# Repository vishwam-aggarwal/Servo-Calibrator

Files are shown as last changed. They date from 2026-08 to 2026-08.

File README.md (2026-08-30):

# Servo Calibrator

A browser-based tool that characterizes a hobby RC servo — finds its real
pulse range and builds a 20-point calibration lookup table, fully
automated, one button — then lets you drive and visualize trajectories
against that calibration live, using an AS5600 magnetic encoder as
ground truth instead of a protractor and guesswork.

**Purely for characterization.** This tool doesn't generate a driver
constructor, doesn't ask about horn installation, direction, or a
logical zero point — it always works in the servo's own physical frame,
`[0, maxAngle]`. Turning a measured range/table into an actual
`RCServoMotorDriver`/`PCA9685MotorDriver` constructor (direction, mounting
offset, logical framing) is an application concern, left to your own
[Universal-Motor-Interface](#the-calibration-table--universal-motor-interface)
code.

No install, no build step. It's one HTML file that talks to an Arduino
over [Web Serial](https://developer.mozilla.org/en-US/docs/Web/API/Web_Serial_API).

> **Status:** the firmware is a self-contained FSM (`ServoCalibrator_Companion.ino`)
> verified against real hardware — most recently a full
> `CAL` → `GETTABLE` → `GO` round trip on an Arduino Nano R4, where a
> 20-point table cut mean positioning error from 3.13° (naive linear) to
> **0.19°** across five targets. The app (`website/app.html`) was
> rewritten against that firmware and verified against the real page
> code — real captured hardware wire data fed straight into `SerialLink`,
> calibration parsing, and the charts — but **not yet exercised through
> an actual live `navigator.serial` session** (the browser's native port
> picker needs a human at the keyboard; that pass is still open). See
> [Known limitations](#known-limitations) for what's still rough. **The
> firmware depends on three sibling libraries — Universal-Encoder-Interface,
> Universal-Trajectory-Interface, and the Universal-Device-Interface base
> they both build on — plus RobTillaart's `AS5600`. All public, no private
> access needed** — see
> [Dependencies](#requirements--dependencies) before you try to build it.

## Contents

- [Why this exists](#why-this-exists)
- [Quick start](#quick-start)
- [What it looks like in use](#what-it-looks-like-in-use)
- [How it works](#how-it-works)
- [The calibration table & Universal-Motor-Interface](#the-calibration-table--universal-motor-interface)
- [Export](#export)
- [Wiring](#wiring)
- [Requirements & dependencies](#requirements--dependencies)
- [Safety notes](#safety-notes)
- [Serial protocol reference](#serial-protocol-reference)
- [Known limitations](#known-limitations)
- [License](#license)

## Why this exists

Hobby servos have a real, measurable non-linear bow in their pulse↔angle
response — a plain 2-point linear formula (the usual assumption) leaves
several degrees of avoidable error on the table. Characterizing that
curve by hand (jogging pulses, reading a protractor, building a table
yourself) is slow and imprecise. This tool automates the whole thing: an
AS5600 magnetic encoder on the servo's output shaft gives ground-truth
angle feedback, and the firmware itself stall-scans the servo's real
mechanical limits and sweeps the full range to build a direction-averaged
lookup table — no hand-measurement, no guessing. Then, because the same
rig is already wired up, it doubles as a small live trajectory
visualizer — closer to a mini ODrive GUI than a calibration wizard — so
you can actually *see* what that calibration buys you before writing any
application code.

## Quick start

1. **Install the four libraries this firmware needs** — all free,
   no private access required (see
   [Requirements & dependencies](#requirements--dependencies)):
   - **`AS5600`** (RobTillaart's), via the Arduino IDE's own Library
     Manager: `Sketch → Include Library → Manage Libraries…`, search
     `AS5600`, install the one by RobTillaart. Or from the command line:
     `arduino-cli lib install "AS5600"`. Still needed — the firmware
     reaches it through Universal-Encoder-Interface rather than directly,
     but that's a wrapper, not a replacement.
   - **[Universal-Encoder-Interface](https://github.com/vishwam-aggarwal/Universal-Encoder-Interface)**
     — install manually, same as the two below. Provides
     `AS5600EncoderDriver`, which owns the multi-turn (across-revolution)
     position tracking this firmware depends on.
   - **[Universal-Trajectory-Interface](https://github.com/vishwam-aggarwal/Universal-Trajectory-Interface)**
     — not in Library Manager's index (it's not a published Arduino
     library, just a public GitHub repo), so install it manually:
     download the repo as a ZIP from GitHub (`Code → Download ZIP`) and
     use `Sketch → Include Library → Add .ZIP Library…`, pointing at
     that ZIP — the IDE unpacks it into your sketchbook's `libraries/`
     folder itself. (Equivalently: `git clone` it directly into your
     Arduino `libraries/` folder, e.g.
     `~/Documents/Arduino/libraries/Universal-Trajectory-Interface` — same
     result, no rename needed since the repo already has a proper
     `library.properties`.) Restart the IDE afterward if it was already
     open, so it picks up the new library.
   - **[Universal-Device-Interface](https://github.com/vishwam-aggarwal/Universal-Device-Interface)**
     — the foundation layer both of the above declare, so it's needed even
     though this firmware never includes anything from it directly.
     Universal-Encoder-Interface's `IEncoder` derives from its `IDevice`;
     separately, the Arduino IDE compiles every `.cpp` in a library's
     `src/`, so Universal-Trajectory-Interface's `TrajectoryGroup.cpp` /
     `CartesianMove.cpp` (neither of which this sketch uses) pull in
     `<IDevice.h>` regardless. Without it the build stops at
     `fatal error: IDevice.h: No such file or directory`. Install it
     exactly the same way as above (ZIP or `git clone` into
     `libraries/`), also public.
2. **Flash the firmware.** Open `ServoCalibrator_Companion/ServoCalibrator_Companion.ino`
   in the Arduino IDE (or `arduino-cli`) and upload it to your board.
   Servo signal is fixed at pin `A3` (change `SERVO_PIN` in the sketch if
   you need a different pin — unlike the firmware's predecessor, this
   isn't runtime-configurable, since there's no wizard step left to ask).
3. **Wire it up**: servo signal to `A3`, AS5600 on the board's I²C bus
   (`SDA`/`SCL`), servo power from an external supply sized for your
   servo (not the Arduino's own 5V pin on most boards — see
   [Wiring](#wiring)).
4. **Open the app.** `website/app.html` needs to be served over
   `http://` — Web Serial does not reliably work when a page is opened
   directly as a `file://` URL. (A hosted copy is also planned at
   [vishwamaggarwal.com/tools/servo-calibrator/](https://vishwamaggarwal.com/tools/servo-calibrator/),
   once that page is out of draft — no local setup needed there.) The
   easiest way to run it from this repo in the meantime:
   ```bash
   # from website/
   python -m http.server 8000
   # or: npx serve
   ```
   then open `http://localhost:8000/app.html` in **Chrome or
   Edge** (Web Serial isn't implemented in Firefox or Safari).
5. **Connect, then Calibrate.** Click *Connect…*, pick your serial port
   in the browser's device picker, then click **Calibrate** — one
   button, fully automated, usually done in under a minute. The command
   acknowledges immediately and the run streams progress asynchronously;
   the command/chart interface below unlocks once the app sees the
   table finish (there's no separate "done" reply — see
   [Serial protocol reference](#serial-protocol-reference)). Every large
   move the firmware makes during calibration is deliberately slow and
   incremental (small steps, a short pause between each) rather than one
   instant jump — found to be necessary against at least one real servo
   that behaved oddly when commanded a big pulse change in one shot (see
   `CLAUDE.md` for the story); it's expected, not a stall. This firmware
   doesn't remember a calibration across a reconnect — recalibrate fresh
   every session.

## What it looks like in use

- **Calibration**: click Calibrate. The firmware coarse-then-fine scans
  outward from center in both directions — each scan self-calibrates its
  own baseline step rate from its first few real steps, then watches
  every step after that for a weak, reversed, or oversized-jump response
  *relative to that rate* (no fixed threshold) — to find the real safe
  pulse range, then sweeps it twice (once each direction) to build a
  20-point direction-averaged table. Progress streams into the log live.
  Result: a summary (`350–2630µs · 214.01° stroke · 20-point table`) and
  an **Export table…** button.
- **Live trace**: command a single point-to-point move (a real,
  v<sub>max</sub>/a<sub>max</sub>-limited trapezoidal move to a target
  angle — no continuous square-wave/sine-wave generator; this firmware
  deliberately only ever streams one planned move at a time). Three
  auto-scaled rolling charts (position, velocity, error) show setpoint
  vs. AS5600-measured actual, live — velocity's "actual" trace comes
  straight from the firmware's own encoder-derivative measurement, not a
  client-side numeric differentiation.
- **See the table's improvement, interactively**: a toggle switches
  between the plain 2-point linear formula and the just-calibrated
  20-point table (at rest only — like every other command, `MODEL` is
  rejected while a move is actively running) — and the error chart's
  line is colored by which model was active, next to a running
  mean-error-per-model comparison, so the improvement is something you
  watch happen, not a number you take on faith.

## How it works

Two pieces:

- **`ServoCalibrator_Companion.ino`** — a self-contained finite state
  machine, one `switch`/`case` in `loop()`, fixed 50Hz tick, running
  both the calibration routine and trajectory execution itself,
  on-device. Unlike a blocking one-shot design, `CAL` acknowledges
  immediately and the calibration routine runs as part of the normal
  tick loop — the board never stops responding to serial while it runs
  (`PING`/`ABORT` both still work mid-calibration). Once calibrated,
  [`TrapezoidalProfile`](https://github.com/vishwam-aggarwal/Universal-Trajectory-Interface)
  is planned/evaluated on-device at that same fixed ~50Hz, alongside
  telemetry that streams unconditionally every tick regardless of
  state — the app never paces the motion, it only sends target/limit
  commands and plots what comes back. Every encoder read goes through
  [`AS5600EncoderDriver`](https://github.com/vishwam-aggarwal/Universal-Encoder-Interface)
  in continuous mode, which is what keeps the angle accumulating across
  full revolutions instead of snapping back at each wrap — the firmware
  used to do that unwrapping itself and no longer does.
- **`website/app.html`** — the app. Connection, calibration
  triggering/export, and the three live charts all live here; the
  firmware doesn't know anything about SVG or the exported `.h` file's
  format. The firmware's own calibration table is re-anchored to a 0°
  low endpoint on-device (see
  [Serial protocol reference](#serial-protocol-reference)), so the app
  no longer does any of that framing itself — it just plots/sends what
  the firmware already reports in the established physical
  `[0, maxAngleDeg]` convention.

## The calibration table & Universal-Motor-Interface

The table this tool builds is a plain array of `{pulseUs, angleCentideg}`
pairs (`CalPoint`) — the firmware's own self-contained type, **not**
an include of [Universal-Motor-Interface](https://github.com/vishwam-aggarwal/Universal-Motor-Interface)'s
`ServoCalibrationTable.h` (building/uploading this sketch needs no UMI
access at all — see [Requirements & dependencies](#requirements--dependencies)).
It's deliberately shaped like UMI's own `CalPoint` — same fields, same
angle↔pulse interpolation algorithm — but not identical (`int32_t`
angles here vs. UMI's `int16_t`, to handle this firmware's unbounded
multi-turn position tracking) and lives entirely in `ServoCalibrator_Companion.ino`
itself. The table is also normalized to the same `[0, maxAngleDeg]`
frame UMI's `validateCalTable()` expects (index 0 at exactly 0°,
strictly ascending) — done on-device, once, right when a calibration
finishes, so `GETTABLE`'s own wire output already satisfies it with no
client-side transform needed. Export (see [below](#export)) generates a
standalone `.h` file with a plain `CalPoint` struct and populated array
in that exact shape, to hand to `RCServoMotorDriver`'s/`PCA9685MotorDriver`'s
table-accepting constructor overload by whatever *consuming* application
installs this servo (one edit needed first — those drivers require a
`PROGMEM` table; see [Export](#export)) — that's where UMI actually comes in, downstream,
not in building this tool. Physical testing
across two servos (140 to 22,000+ samples, in the investigation that
motivated this whole tool) found a 20-point table cuts mean positioning
error 2–6× vs. the linear formula, for ~80 bytes of `PROGMEM`.

**This tool deliberately doesn't generate the constructor call itself.**
The old wizard-based version of this repo did (see git history) — this
version doesn't, because direction, logical zero, and mounting offset are
all *installation*-specific decisions this characterization-only tool has
no way to know. Export the table (see [below](#export)) — it's already a
`CalPoint` array in the right shape and framing, no manual transcription
needed — add `PROGMEM` to its declaration (see [Export](#export) for why
that one edit isn't optional), and pass it to
`RCServoMotorDriver`'s/`PCA9685MotorDriver`'s table-accepting
constructor overload alongside whatever direction/offset your actual
installation needs.

## Export

**Export** queries the firmware for its current table (`GETTABLE`, a
genuine on-demand round trip, not a reuse of whatever the app happened to
capture live off the original `CAL` run's own `TABLE` stream) and
downloads it as a standalone `.h` file: a plain
`struct CalPoint { uint16_t pulseUs; int16_t angleCentideg; }` — matching
UMI's own `ServoCalibrationTable.h` field-for-field, though the file
itself never mentions UMI — plus a populated
`static const CalPoint SERVO_CAL_TABLE[]` array, already in the firmware's
own `[0, maxAngleDeg]` framing (see
[How it works](#how-it-works)). It's a plain RAM array, not `PROGMEM` —
directly readable with no special macro whether or not the consuming
code ever touches UMI.

> **Add `PROGMEM` before handing it to a UMI driver.** This is not the
> optional flash-vs-RAM tradeoff it reads like. UMI's
> `ServoCalibrationTable.h` reads every entry through `readCalPoint()`,
> which calls `pgm_read_word()` unconditionally — so on AVR, where flash
> and RAM are separate address spaces, passing a plain RAM array to
> `RCServoMotorDriver`/`PCA9685MotorDriver` reads flash at the same
> numeric address and gets garbage. In practice `validateCalTable()` then
> rejects the nonsense (the driver falls back to the linear formula and
> reports `ERR_INVALID_CAL_TABLE` once), so it isn't silent — but it also
> isn't the table you measured. Add `PROGMEM` to the array declaration
> and it works as intended. The exported file says the same thing in its
> own header comment, phrased generically, since it's deliberately
> written to be usable outside UMI too.

Note also that the emitted `angleCentideg` field is `int16_t`, matching
UMI's `CalPoint` — so it tops out at 327.67°. The firmware's own table is
`int32_t` and has no such limit, so Export refuses outright (rather than
writing a table that would silently wrap once compiled) if a servo ever
measures a stroke past that. There's no matching **Import** — this
firmware has no command that accepts a pushed-in table, unlike its
predecessor. `GETTABLE` only ever answers for the *current* session,
too: opening the port always reboots the board, wiping its table, so
every reconnect still needs a fresh Calibrate before Export works again.
Export exists purely for keeping a record of what a servo measured at,
not for skipping a future physical recalibration of that same servo.

## Wiring

- **Servo signal** → `A3` (fixed in firmware — see [Quick start](#quick-start)
  if you need a different pin).
- **AS5600** → the board's I²C bus (`SDA`/`SCL` — `A4`/`A5` on an
  Uno/Nano), with the magnet mounted on the servo's output shaft, centered
  over the chip.
- **Servo power** → an external supply sized for your servo's stall
  current, **not** the Arduino's own 5V/Vin pin on most small boards —
  clone/small-board regulators usually can't source enough current, and
  Vin specifically needs headroom above 5V to regulate down cleanly (it
  is not a direct 5V input). Common ground between the supply, the servo,
  and the Arduino either way.

## Requirements & dependencies

**Hardware:**

- An Arduino-compatible board with I²C and a free PWM-capable digital
  pin (`A3` by default).
- An AS5600 breakout, magnet mounted on the servo's output shaft.

**Software, to build the firmware:**

| Library | Used for | Status |
|---|---|---|
| [RobTillaart's `AS5600`](https://github.com/RobTillaart/AS5600) | Low-level AS5600 I²C register access | Public — `arduino-cli lib install "AS5600"` or via Library Manager |
| [**Universal-Trajectory-Interface**](https://github.com/vishwam-aggarwal/Universal-Trajectory-Interface) (mine) | `TrapezoidalProfile` — used **unconditionally** | **Public** |
| [**Universal-Encoder-Interface**](https://github.com/vishwam-aggarwal/Universal-Encoder-Interface) (mine) | `AS5600EncoderDriver` — the AS5600 read path and its multi-turn unwrap | **Public** |
| [**Universal-Device-Interface**](https://github.com/vishwam-aggarwal/Universal-Device-Interface) (mine) | Nothing, directly — it's the base both siblings above declare (`depends=Universal Device Interface`), and the Arduino IDE compiles a library's whole `src/` regardless of what the sketch includes | **Public** |

In short: anyone with these four libraries installed (see
[Quick start](#quick-start)) can build and upload this firmware —
**no private dependency remains**. Universal-Device-Interface joined the
list on 2026-08-29, when Universal-Trajectory-Interface's `TrajectoryGroup`
and `CartesianMove` were retrofitted onto its shared `IDevice` base; the
per-axis profile math this firmware actually uses (`TrapezoidalProfile`)
was deliberately left off that base and is unchanged, so that library is
purely an install-time requirement here, not an API change.
Universal-Encoder-Interface joined at the same time, when this firmware's
hand-rolled AS5600 multi-turn tracking was replaced by its
`AS5600EncoderDriver`.

> **On an ATmega328P specifically** (the classic Nano this project was
> developed on), the firmware now uses 78% of SRAM and `arduino-cli`
> prints `Low memory available, stability problems may occur`. About 230
> bytes of that is structural rather than avoidable: on AVR a class's
> diagnostic strings live in RAM, and Universal-Encoder-Interface's
> `IDevice` vtable keeps every one of `AS5600EncoderDriver`'s reachable
> whether this sketch calls them or not. It builds and links cleanly, and
> there is no such pressure on a 32-bit board (an Arduino Nano R4 comes in
> at 22% of its SRAM) — but on a 328P, that's the first thing to suspect
> if you hit instability.

`ServoCalibrator_Companion` does
**not** depend on Universal-Motor-Interface, despite an earlier version
of this doc claiming otherwise — its calibration-table code (`CalPoint`,
angle↔pulse interpolation) is a self-contained reimplementation in the
`.ino` itself, not an actual include of UMI's `ServoCalibrationTable.h`.
See [The calibration table](#the-calibration-table--universal-motor-interface)
below for where UMI *is* still relevant (downstream, for a consuming
application), just not for building this sketch.

**Browser:** Chrome or Edge (desktop) — Web Serial isn't available in
Firefox or Safari.

## Safety notes

- **Calibrate with a bare horn.** No linkage, mechanism, gearbox, or load
  attached — a loaded mechanism can make a stall look like normal
  resistance and vice versa. Recalibrate (re-run `CAL`) if you change the
  mechanical load after the fact.
- `CAL` deliberately drives the servo into its mechanical end stops to
  find them (with active recovery if the servo spins past a limit
  instead of stalling, rather than just timing out — see `CLAUDE.md`).
  It stops advancing within a small margin of first detecting no motion,
  so it only grinds against a stop briefly — but it is intentionally
  doing that, twice (once per direction), by design.
- A hard pulse-width safety ceiling (80–2912µs, fixed in firmware) exists
  as a fail-safe in case stall detection doesn't trigger for some reason
  (e.g. an encoder fault) — a scan hitting it ends the run without a
  usable table, rather than silently accepting a bad range. If that
  happens to you, it likely means your servo's real range is wider than
  this default too — widen `ABS_FLOOR_US`/`ABS_CEIL_US` in the firmware
  and reflash. **Don't raise `ABS_CEIL_US` past 2912µs**: the AVR `Servo`
  library encodes `attach()`'s bounds in a signed `int8_t`, and anything
  higher silently overflows and wraps to a *lower* effective ceiling than
  before (2912 is the real representable max — see `CLAUDE.md`'s
  2026-08-25 entry for how this was found and what it cost).

## Serial protocol reference

115200 baud, one command per line, newline-terminated ASCII. Genuinely
different in shape from the predecessor firmware this repo used to have
at this path — see `CLAUDE.md`'s 2026-08-21 entry for the full design
story if you're diffing against an older version of this doc.

| Command | Response |
|---|---|
| `PING` | `OK PING` |
| `CAL` | `OK CAL` — acknowledges immediately; the run itself streams asynchronously (see below), no final reply |
| `ABORT` | `OK ABORT` \| `ERR ALREADY_IDLE` — cancels a calibration *or* a move; exempt from the busy-gate below |
| `ACCEL <aMaxDegS2>` | `OK ACCEL` |
| `VEL <vMaxDegS>` | `OK VEL` |
| `POS <targetDeg>` | `OK POS` \| `ERR NOT_CALIBRATED` \| `ERR POS_RANGE` — range-checked server-side against `[0, maxAngleDeg]` (the app also checks client-side first, to fail fast without a round trip) |
| `GO` | `OK GO` \| `ERR NOT_CALIBRATED` — starts a move to the most recently set `POS`, at the most recent `ACCEL`/`VEL` |
| `MODEL LINEAR\|TABLE` | `OK MODEL` \| `ERR NOT_CALIBRATED` |
| `GETTABLE` | `OK GETTABLE` \| `ERR NOT_CALIBRATED` — streams all 20 `TABLE` lines first (see below), *then* replies; no immediate ack the way `CAL`/`GO` get one |

While a calibration or move is running, every command except `ABORT` and
`PING` is rejected with `ERR BUSY`.

**Calibration streams three line shapes while it runs**, none of them a
reply to any pending command:

```
<elapsedMs> PROGRESS <stateName> <tick> <lastSentUs> <posCentideg>
<elapsedMs> TABLE <index> <pulseUs> <angleCentideg> <posCentideg>
<elapsedMs> ERR <code> <posCentideg>
```

That trailing `<posCentideg>` is a diagnostic field every one of these
lines carries: the current *filtered* shaft position, in raw-frame
centidegrees (relative to wherever the board booted, **not** normalized
to `[0, maxAngleDeg]`). It used to be raw AS5600 counts; it became
centidegrees when the encoder path moved to Universal-Encoder-Interface
and the internal position stopped being counts at all. Nothing parses
it — the app reads the fields ahead of it and ignores this one — so
treat it as a log aid, not protocol.

`TABLE` fires twice per index (20 points, down-pass then up-pass —
the up-pass value is the final, direction-averaged one); the app detects
completion by recognizing index 19 arriving *ascending* (immediately
after index 18), since there's no dedicated "done" message. `angleCentideg`
in this **live, mid-calibration** stream is still a **raw** encoder
reading relative to wherever the board happened to boot — normalization
only happens once, in memory, right after both passes finish (see
[How it works](#how-it-works)), so these in-flight lines are
progress-only; the app doesn't build the final calibration from them
any more, it just watches the index sequence for completion. `ERR` here
is an asynchronous internal failure (e.g. a settle timing out), not a
synchronous command rejection.

`GETTABLE` streams the identical `TABLE` line shape, once per index,
ascending — one entry per tick, oldest first, no down/up-pass repeat
this time (it's just replaying the already-built table, not measuring a
fresh one). Unlike the live stream above, `GETTABLE` always reflects the
table *after* normalization — index 0 at exactly 0°, strictly ascending
— since it's reading `calTable` at rest, not mid-scan. The app tells a
live-CAL `TABLE` line apart from a `GETTABLE` one by whether a
calibration is actually running, not by the line shape itself (same
shape either way), and always calls `GETTABLE` once calibration
completes to get the authoritative normalized table rather than trusting
what it watched go by live.

Telemetry streams every tick (~50Hz) from boot onward, unconditionally
— not only once calibrated, and regardless of state (idle,
mid-calibration, or mid-move):

```
TELEM <ms> <targetCentideg> <targetVelCentidegPerSec> <actualCentideg> <actualVelCentidegPerSec>
```

No mode/model field (unlike the old `T,...` line) — the app tracks which
model is live itself, since only it ever changes `MODEL`. A completed
move is signaled by exactly one `PROGRESS TRAJ_WAIT ...` line, printed
the instant the shaft settles. Lines starting with `#` are informational
(boot banner) — not part of the command/response or telemetry protocol.

## Known limitations

- **The browser app hasn't been exercised against a real live serial
  connection yet** — verified by feeding real captured hardware wire
  data directly into the actual page code (`claude-in-chrome`, not a
  reimplementation), but the `navigator.serial` port-picker itself needs
  a human at the keyboard to click through, and that pass hasn't
  happened yet.
- **No calibration persists across a reconnect.** `GETTABLE` can
  re-query the current session's table (used by Export), but opening the
  port always reboots the board — recalibrate every session regardless.
- **No table import**, only export — there's no command this firmware
  accepts a pushed-in table through. Export is for record-keeping, not
  for skipping a future recalibration.
- Tested on Chrome/Edge over `http://localhost`; opening the app
  directly via `file://` has not been confirmed to work reliably with
  Web Serial.
- No PCA9685 support in this firmware (the old wizard-era version had
  it; this characterization-only rewrite doesn't yet — `ServoCalibrationTable.h`'s
  math is transport-agnostic, so adding it back is mostly a matter of
  swapping the raw `Servo` calls for `PCA9685Backend` ones).
- Servo pin is fixed at compile time (`A3`) — no runtime pin
  configuration, unlike the old wizard-era firmware.
- No installer/packaged build — meant to stay a single portable HTML
  file, served locally.

Issues and pull requests welcome.

## License

MIT — see [`LICENSE`](LICENSE).

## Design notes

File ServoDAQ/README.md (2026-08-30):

# ServoDAQ

A second, unrelated tool in this repo — a companion firmware
(`ServoDAQ_Companion/ServoDAQ_Companion.ino`) plus a Python host driver
(`ServoDAQ_Host/`), not the Web-Serial browser app documented in the
[main README](../README.md). It exists for one-off bench
characterization/article-testing work — comparing a naive single-step
stall-detection sweep against a smarter coarse+fine, rate-based
`find_range()` on real hardware — and is deliberately kept separate from
`website/app.html`/`ServoCalibrator_Companion`: that tool stays
untouched, this kind of exploratory work goes in its own files instead.

No zero reference, no model, no calibration table — that's the host's
job. The firmware's only responsibilities are talking to the servo,
reading the AS5600, and turning that into a signed, monotonic,
multi-turn-unwrapped centidegree position (see the `.ino`'s own
file-level comment for how). Everything else — range-finding, deciding
what "the edge" means, plotting — lives in `ServoDAQ_Host/`.

**Libraries needed to build the firmware** (all public): RobTillaart's
`AS5600`, plus Universal-Encoder-Interface and its own base
Universal-Device-Interface. As of 2026-08-29 the multi-turn unwrap is
Universal-Encoder-Interface's `AS5600EncoderDriver` (continuous mode)
rather than a copy maintained here; the wire protocol is unchanged.

## Protocol

115200 baud, one command per line, `\n`-terminated ASCII.

- `PING` → `OK PONG`
- `US <pulseUs>` → `OK <pulseUs> <centideg>` (blocks until settled) |
  `ERR NOT_SETTLED <pulseUs> <centideg>` (the settle timeout elapsed
  without ever meeting the criterion — `centideg` here is just the last
  raw reading, not a trustworthy position; see "A servo that spins a
  full turn instead of stalling" below for why this reply exists)
- `CAP <pulseUs> <delayMs>` → streamed `CP <tMs> <centideg>` samples,
  `CAPEND <count>` — diagnostic raw step-response capture, for seeing
  motion the settle detector smooths over.

## Host scripts

- `servo_daq.py` — the library: `ServoDAQLink`, `sweep()`,
  `naive_stall_sweep()` (the dumb baseline), `find_range()`/`find_edge()`/
  `scan_until_weak()` (the coarse+fine rate-based algorithm).
- `study_range.py` — the full per-servo characterization pipeline, one
  connection/session: naive sweep → smart `find_range()` → fine (5µs,
  both directions) calibration sweep → N-point lookup-table accuracy
  test (see below). Written to run identically across different servos
  (same code path/phases/thresholds every time) — only the port and the
  accuracy-test duration are meant to vary between invocations.
- `plot_naive_vs_smart.py` — same comparison, but plots naive/coarse/fine
  as three separately colored traces (one connection/session, so the
  centideg reference is consistent across all of it).
- `plot_full_range.py` — reads a saved run's CSVs (no hardware access)
  and draws one combined-axis chart spanning the whole tested range, with
  markers at `find_range()`'s reported min/max.
- `probe_low_jump.py`, `hand_stall_test.py`, `watch_full_swing_jump.py`,
  `full_test_record.py` — the diagnostic scripts written for the
  investigation below. Deleted 2026-08-19 once their findings were fully
  captured here and in `CLAUDE.md`: ad hoc debugging tools for that
  specific, already-resolved question, not part of the standard
  `study_range.py` procedure. Still recoverable from git history.

`../data/` holds whatever a given run saved (CSVs + PNGs) — regenerated
each session, not version-controlled.

## Investigation: a real stall-recovery backoff, not a bug (2026-08-16)

First real `find_range()` comparison against a second (digital) servo
showed the naive and smart low-side edges disagreeing by roughly 300°
— naive settling around 310–320µs at a wildly different reported angle
than smart's 345–350µs. The high side never showed this; only the low
side, and only past where the smart algorithm's own weakening detector
already flags the real edge.

Six theories were ruled out in order, each on direct evidence rather
than assumption:

1. **Unwrap algorithm bug.** A `CAP`-based fine-grained capture
   (`probe_low_jump.py`, 30ms/sample) across the transition showed a
   smooth, monotonic ~31,000-centideg climb over ~1.6–1.8s — not a
   single discontinuous jump between adjacent samples. `updatePositionTracking()`'s
   wrap detection only misfires on a genuine same-tick discontinuity
   bigger than half a revolution; this wasn't one.
2. **A stray/bad AS5600 sample.** A single bad reading doesn't
   reproduce the same magnitude and S-curve shape (slow start, ramp,
   decelerate to a clean stop) across independent runs. This did,
   repeatedly.
3. **Real horn rotation.** Directly watched: the horn did not move
   during an early capture that still showed the full climb on the
   encoder.
4. **Magnet/sensor mounting.** Magnet and sensor were fully reseated;
   the anomaly's magnitude was unchanged (~311° vs. ~313°) and it still
   happened on the same side at the same threshold. A loose mount would
   have changed something.
5. **Shared power supply (voltage sag under stall current).** Ruled out
   directly — the AS5600 runs on a separate, regulated supply.
6. **Shared ground (conducted ground bounce under stall current).**
   Ruled out directly — the ground is a star topology, not shared with
   the servo's return path.

The actual mechanism, confirmed two ways:

- **Watched it happen.** Using `watch_full_swing_jump.py` (drive to max,
  then min, pause, then command past the edge) and `full_test_record.py`
  (the same sequence, but recorded continuously — a stitched
  pulse-vs-time and angle-vs-time chart across the whole thing, not just
  the final leg), the horn was directly observed to reverse and rotate
  ~300° over about 1.5–2s, matching the encoder's own timing and
  magnitude exactly.
- **Servo-disconnected control.** With the servo physically unpowered
  (zero current, motor fully disconnected), the identical command
  sequence produced a perfectly flat reading (±1 count of sensor jitter)
  for a full 3-second capture — no drift at all. The effect requires the
  motor to be powered and drawing current; it isn't in the sensor, the
  firmware, or the unwrap math, all of which ran the exact same code
  path in both cases.

**Conclusion:** this digital servo has its own internal stall/overcurrent
protection. Driven hard enough past its real mechanical limit for long
enough, it deliberately repositions itself away from the stall — a real,
controlled, servo-executed move (hence the realistic accelerate/cruise/decelerate
shape), not a sensor artifact. `find_range()`'s coarse+fine algorithm had
been avoiding this by luck: its fine scan's small steps and immediate
stop-on-first-weakness happened to back off before ever dwelling in a
hard stall long enough to trigger it. The coarse scan (50µs steps) had
much less margin — and did in fact hit the real thing live during
testing, walking 350→300µs in one step and landing squarely in the
backoff (see `plot_full_range.py`'s output, and the fix below).

### The fix

`scan_until_weak()` (`ServoDAQ_Host/servo_daq.py`) previously only
checked for steps *smaller* than its own self-measured reference rate
(weakness). It had no defense against a step that's backwards or
implausibly large, so a coarse step landing in a hard stall would be
silently accepted as if it were a genuine, fast edge.

It now also ends the scan — handled exactly like reaching a weak step,
not raised as an error — when a step's delta reverses direction relative
to the scan itself, past the same noise floor weakness already uses (so
ordinary ±1-count sensor jitter while genuinely stopped never trips it).
No separate magnitude/"too-large" check or fixed absolute-degree glitch
filter was added — every backoff observed on real hardware was a
reversal, never a same-direction overshoot, which is what "backing off
from an over-extension" should physically look like. `find_edge()`
recovers through its existing fine-pass fallback automatically; no
caller-side changes were needed.

Verified live: `find_range()` now completes cleanly through a run that
previously would have returned a corrupted low edge (350µs, matching
every other clean run), with no false positive on the unaffected high
side.

**Open question, not yet answered:** the exact trigger condition (how
much cumulative stall dwell time is required) isn't characterized —
different runs triggered it with and without a deliberate extra pause.
`find_range()`'s current safety margin against this is real (verified
above) but not precisely measured.

## N-point lookup-table accuracy test (2026-08-17)

`study_range.py`'s third phase, once the fine (5µs) calibration sweep
is captured: direction-averages the up/down sweep into one ground-truth
pulse→angle curve, builds a 2-point linear baseline and 10/20/30/40/50-
point lookup tables from it (`build_table()` — evenly spaced by pulse,
each breakpoint snapped to an actually-measured grid point, not a
fabricated interpolation), then validates against **real hardware**:
repeatedly picks a target angle, computes a model's predicted pulse for
it via `angle_to_pulse()` (binary search + linear interpolation, same
algorithm the real embedded tools use, run in the angle→pulse direction
since that's the actual usage this validates), commands it, and measures
the real resulting angle. This is the actual end-to-end accuracy that
matters — how close the servo lands to where you asked it to go — not a
synthetic curve-fit residual.

Runs to a wall-clock deadline, not a fixed sample count, so a multi-hour
run just works. Two explicit safety measures, both requested after a
servo has died from exactly this kind of unattended extended-duration
stress before: a 1-second rest after every single move, and every
predicted pulse clamped to `[min_pulse_us, max_pulse_us]` regardless of
what the interpolation computes — the test never drives the servo
anywhere the fine sweep didn't already prove is safe. Data safety:
phase-1 results are saved to disk *before* the accuracy test starts, and
every trial row is flushed immediately, so a crash or interruption deep
into an hours-long run never risks losing everything before it.

### A real methodological flaw, caught and fixed the same day

**First run** (stamp `20260817-005841`, since superseded): paired one
target angle with all 6 models per round, model order shuffled within
the round. This clustered 5 of 6 moves per round into ~3µs nudges
between nearly-identical predicted pulses — all 6 models predicting
close together for the same angle — too small to decisively re-engage
the servo's mechanism, letting real backlash/deadband play show up as
scatter unrelated to any model's actual accuracy. Worse: whenever
`linear2` wasn't first in its round, the servo was already sitting near
the *good* answer because a table model had just moved there chasing the
same target — quietly flattering the naive baseline.

Diagnosed directly, not assumed: mean\|err\| by position-within-round
climbed steadily (0.315°→0.402° across positions 2–6) while raw jump
*distance* showed no correlation with error at all (even 1000+µs jumps
had the lowest mean error of any bucket), and signed error stayed ~0 at
every position — ruling out both "big jumps settle badly" and a
directional bias, and pointing specifically at growing *scatter* from
near-zero-delta moves within a round.

**Fix**: `run_accuracy_test()` decouples target angle and model
completely — every trial is fully independent, its own random angle
*and* its own independently-chosen model (drawn from a shuffled bag that
refills on empty, so sample counts stay balanced across models over the
run, not just in expectation). Every move is now a genuine, decisive
jump; no model can benefit from another model's positioning.

**Corrected run** (stamp `20260817-114844`): 3 hours unattended, 6493
fully independent trials (~1082/model).

| model | points | mean\|err\| | median\|err\| | p90\|err\| | max\|err\| | rms |
|---|---|---|---|---|---|---|
| linear2 | 2 | 0.938° | 0.865° | 1.822° | 3.896° | 1.131° |
| table10 | 10 | 0.344° | 0.264° | 0.691° | 2.572° | 0.476° |
| table20 | 20 | 0.338° | 0.252° | 0.670° | 2.594° | 0.488° |
| table30 | 30 | 0.339° | 0.256° | 0.658° | 2.992° | 0.479° |
| table40 | 40 | 0.319° | 0.250° | 0.617° | 2.671° | 0.443° |
| table50 | 50 | 0.312° | 0.247° | 0.596° | 2.427° | 0.427° |

The real margin is much larger than first measured: mean error drops
~63-67% (0.94°→0.31-0.34°), median ~69-71%, RMS ~58-62%, across every
table size — the flawed run had reported only ~25-29%/~33-35%/~20-27%.
`linear2`'s real error also isn't uniform across the range: it climbs
steeply toward one end (angle-decile means ~0.37°→~1.87° peak, the
textbook signature of a straight line failing where the real curve bows
away from it), while even `table10` stays roughly flat (~0.28-0.46°)
everywhere. `linear2` was never actually competitive — the flawed
methodology just hid it by letting it borrow better models' positioning.

Diminishing returns past ~20-30 points still holds: `table20` through
`table50` cluster within ~0.03° of each other on mean error;
consistent with this project's existing 20-point convention not being
undersized for a servo like this one.

One methodological lesson, not a servo finding: the flawed run's one
"counterintuitive" result — `table10`'s max error beating `linear2`'s —
didn't survive the fix. In the corrected run `linear2` has the worst max
of all six models. Max is a single-extreme statistic; noisy enough to
flip entirely once a real measurement bias was removed — don't trust a
surprising max comparison until it replicates.

### Two small follow-ups, same day

- **Degrees, not centidegrees, in the accuracy CSV**: `target_angle_deg`/
  `actual_angle_deg`/`error_deg` replace the old `*_centideg` columns —
  this file has no downstream reader in the codebase (only ad hoc
  analysis), so there's no interoperability reason to match the rest of
  the project's centideg convention, and degrees reads far easier raw.
  Internal math is still centidegrees throughout, same as everywhere
  else in this project.
- **`motor_type`/`unit` in every filename** (`type<N>_unit<M>_<timestamp>_*.csv`),
  ahead of the real 8-servo study — see [`MOTOR_TYPES.md`](MOTOR_TYPES.md)
  for the actual inventory. `type0`/`unit0` is reserved for
  unlabeled/test runs when those CLI args are omitted.

Raw data: `ServoDAQ/data/accuracy_trials_20260817-114844.csv` (6493
rows) / `accuracy_summary_20260817-114844.csv` — both untracked, still
on disk locally at time of writing. Not yet done: the same run on the
other 7 servos in `MOTOR_TYPES.md`.

### Degrees in every CSV, not just the accuracy one (2026-08-17)

The "degrees, not centidegrees" fix above only ever touched the
accuracy-trials CSV. A later `type1_unit1` run crashed (laptop failure)
partway through its accuracy phase; that stamp's data was discarded
(the accuracy CSV was itself well-formed up to its last flushed row —
the crash just meant the run never reached its planned duration, not
that anything was corrupted) rather than kept as a partial result.

Before restarting, extended the same fix to every other CSV
`study_range.py` writes — `naive_low/high`, `fine_up/down`,
`smart_coarse/fine_low/high`, and `summary` all now carry `angle_deg`
instead of raw `centideg`, matching the accuracy CSV's own convention.
`plot_naive_vs_smart.py` (which duplicates the same phase-1 CSV writes
for standalone naive-vs-smart runs) got the identical fix.
`plot_full_range.py` — the one script that re-reads these CSVs from
disk instead of plotting from live in-memory data — was updated to read
the new column and relabel its axes/annotations. The four one-off
investigation scripts' raw capture CSVs
(`probe_low_jump.py`/`hand_stall_test.py`/`watch_full_swing_jump.py`/
`full_test_record.py`) got the same treatment for consistency, though
their in-memory-plotted PNGs are unaffected (still centideg, since
those plot straight from the captured trace, never reloading the CSV).

Internal math is untouched everywhere — ground truth, tables, and every
stall/rate threshold still work in centidegrees, same as before; only
the value actually written to a CSV row gets converted, at the point of
writing (`to_deg_trace()` in both `study_range.py` and
`plot_naive_vs_smart.py`). Purely a Python-side change: the firmware
and its wire protocol are untouched. Applied proactively, before
generating any more data, so no future CSV needs a retroactive
unit correction the way the accuracy CSV alone did previously.

### First real unit of the 8-servo study: type1_unit1 (2026-08-17)

Restarted the crashed run above on the now-fully-degrees CSVs: full
`study_range.py COM9 3 1 1` against `type1_unit1` (Miuzei 25kg Servo,
first of 2 units of that type — see `MOTOR_TYPES.md`). Completed
cleanly, no errors, servo returned to center. Stamp
`20260817-170727`.

Phase 1: naive low edge 310µs, naive high edge 2100µs; smart (real)
range 345–2080µs, -38.76° to 194.06° — a ~232.8° stroke, in the same
ballpark as the wide-range digital servo characterized earlier in this
file, though a different physical unit/model.

Phase 2 (accuracy test, 3h, 6482 independent trials):

| model | points | n | mean\|err\| | max\|err\| | rms |
|---|---|---|---|---|---|
| linear2 | 2 | 1081 | 1.0847° | 4.4880° | 1.2196° |
| table10 | 10 | 1080 | 0.3906° | 2.7480° | 0.5305° |
| table20 | 20 | 1080 | 0.3342° | 2.5040° | 0.4590° |
| table30 | 30 | 1081 | 0.3348° | 2.6940° | 0.4765° |
| table40 | 40 | 1080 | 0.2932° | 2.4130° | 0.4134° |
| table50 | 50 | 1080 | 0.3048° | 2.3750° | 0.4325° |

(`summarize_accuracy()` only ever computed mean/max/rms — no median —
same columns as every other run's summary CSV, unchanged by this run.)
The same qualitative picture as the reference run above holds on this
unit too: `linear2`'s mean error
is ~3x any table model's, and returns diminish sharply past ~10-20
points — `table20` sits within noise of `table50` on every metric here.
Nothing in this first unit contradicts the reference run's conclusions;
it reads as a second, independent confirmation on different physical
hardware rather than a new finding.

Raw data: `ServoDAQ/data/accuracy_trials_type1_unit1_20260817-170727.csv`
(6482 rows) / `accuracy_summary_type1_unit1_20260817-170727.csv`, both
untracked, still on disk locally at time of writing. **Remaining**: 7
more units — `type1_unit2`, `type2_unit1` through `unit3`, `type3_unit1`
through `unit3`.

`type1_unit2`'s own full 3h run (stamp `20260818-161957`) hit a
mid-run `PermissionError` on the serial port at trial 3100 (~86.5min
in) — a transient USB/driver drop (the port re-enumerated cleanly once
the process died; reconnecting and recentering worked immediately), not
a firmware or algorithm problem. That partial run's data (523-524
samples/model) was discarded 2026-08-18 rather than kept; a clean full
rerun (stamp `20260818-225108`) is in progress as of this writing.

## Investigation: a servo that spins a full turn instead of stalling, and the settle-report bug that hid it (2026-08-18)

First `study_range.py` run against `type3_unit1` (MG90D) made the
servo start visibly spinning continuously during phase 1, unlike every
unit tested so far. Two real, distinct bugs, found by looking directly
at the data rather than guessing — the second guess (a sensor glitch)
didn't survive scrutiny either, and got retracted on the evidence, not
just abandoned.

### Bug 1: the firmware could ack a move it never actually settled

`reportSettled()` in `ServoDAQ_Companion.ino` was called from both the
real-convergence path (`SETTLE_DWELL_TICKS` of sustained low deltas)
and the timeout path (`SETTLE_TIMEOUT_MS`, 3s, elapsed without that
ever happening) — and sent the *identical* `OK <pulseUs> <centideg>`
reply either way. The host had no way to tell a genuine settle from a
timed-out, possibly-still-moving reading; `converged` only decided
which value got reported (averaged stable window vs. last raw
reading), never reached the wire. Fixed: the timeout case now sends
`ERR NOT_SETTLED <pulseUs> <centideg>` instead — a real, distinct
signal, not a fake success. Verified with `arduino-cli compile`/
`upload` and confirmed live (`PING`/`US` round-trip) before any of the
investigation below.

### Bug 2 (or: not a bug) — this isn't a sensor glitch, it's a real decision boundary

With the honest error visible, the first theory was a stray AS5600
read corrupting the wrap-safe accumulator — the exact failure class
this project already found once before (see "Multi-turn position
tracking" above). It didn't hold up: the observed jump magnitudes
across several incidents (-1246.91°, -2572.73°, -10852.65°, ...)
aren't integer multiples of 360° the way a miscounted-wrap origin
requires (nearest multiples were off by 92-212°), and the implied
angular rate for the *first* incident (~415°/s, ~2.08°/tick at 200Hz)
is far below the ~180°/tick threshold the firmware's own wrap logic
needs to even misfire. The numbers are fully consistent with real,
continuous physical rotation, correctly tracked — not a misread.

Running the actual production functions (`naive_stall_sweep`,
`find_edge`), not a proxy script, showed this isn't rare either: 3-4
out of 5 attempts hit it, consistently landing in a narrow 250-270us
band. A fully instrumented raw-curve probe (5us steps, no stopping
logic at all) showed why no threshold could ever catch it in advance:
the response stays smooth and consistent (~0.2-1.6°/step) right up to
and including the step *immediately before* the failure — if anything
that last step was one of the largest deltas in the whole run, not a
fade toward zero. Sweeping `WEAKENING_FRACTION` from 0.15 to 0.55
confirmed it empirically: every value failed at essentially the same
~250-260us point, because there's nothing in the pre-failure data for
any fraction to key off. Below some pulse threshold, this servo
(explicitly built without mechanical hard stops) takes the commanded
target as a cue to spin the long way around to reach it, instead of
stalling — a discrete decision boundary internal to the servo's own
control logic, not a gradual mechanical/electrical falloff. No amount
of slope-watching can see a step function coming.

### The fix: make crossing the boundary once, safely, part of normal operation

Since the edge can't be predicted in advance, the fix stops trying to
avoid it and instead makes triggering it once cheap and recoverable.
In `servo_daq.py`:

- `naive_stall_sweep()`/`scan_until_weak()` catch `NotSettledError`
  from `move_to()` and treat it exactly like reaching the edge — report
  the last point actually reached normally, stop immediately, never
  take the confirmatory step past a limit that's already proven real.
- `ServoDAQLink.recover_from_wrap()` corrects the position reference
  after recovering: moves to a pulse whose real position is already
  trusted, measures the *actual* drift there (not assumed to be a
  clean -360° — the magnitudes above prove that assumption would be
  wrong), and folds the exact difference into a running
  `centideg_offset` that `move_to()` applies transparently to every
  reading for the rest of the session.
- First end-to-end test (`study_range.py` smoke test) found a real gap
  in that design: the immediate recovery point can *also* land past
  the boundary and fail the same way (the edge isn't perfectly
  repeatable run to run — observed anywhere from 250 to 270us).
  `recover_from_wrap()` now takes an ordered list of fallback
  candidates (nearest first, then the scan's own known-safe starting
  pulse) instead of a single point, caught live from a real crash
  traceback, not anticipated in advance.

Verified on real hardware: 10/10 trials (`naive_stall_sweep` +
`find_edge`, 5x each, low side) completed without raising, edges
consistently found at the real 265-325us limit, reported-position
drift held under 4° across all 10 crossings (the internal
`centideg_offset` climbed past 1.8 million along the way — real
excursions kept happening, just fully corrected for). A full
`study_range.py` smoke test (0.25h, `type3_unit1`) then ran clean
end-to-end, including through a real edge-crossing on the low side —
range found (265-270us to 2075-2100us, -72.6° to 168.7°, ~241°
stroke), accuracy test completed normally (644 trials), servo returned
to center. This is a no-op for any servo that never triggers
`NOT_SETTLED` — `centideg_offset` stays exactly 0 and the new exception
handlers never execute — confirmed by tracing the code paths for
`type1_unit1`/`type1_unit2` (both completed full studies with the old
firmware without ever hitting this), not yet re-verified against their
actual hardware.

`type3_unit1` smoke-test results (stamp `20260818-191520`, ~107
samples/model): same shape as every prior unit — `linear2` mean
1.03°, table models cluster 0.47-0.56°, diminishing returns past
~10-20 points. Smoke test only (15min default), not yet a completed
study unit — the full 3h run is still to do.

### type3_unit1's full study, completed clean (2026-08-18)

Full 3h run (stamp `20260818-194150`) — the first real, complete run on
the `NOT_SETTLED`-fixed firmware: 7766 independent trials, zero
`NOT_SETTLED` events anywhere in the log, zero warnings, servo returned
to center. Range 265-2075µs, -73.6° to 241.6° (~241.6° stroke).

| model | points | n | mean\|err\| | max\|err\| | rms |
|---|---|---|---|---|---|
| linear2 | 2 | 1294 | 1.1274° | 3.3780° | 1.3672° |
| table10 | 10 | 1294 | 0.6587° | 1.7160° | 0.7521° |
| table20 | 20 | 1294 | 0.6225° | 1.7700° | 0.7226° |
| table30 | 30 | 1295 | 0.6244° | 1.8380° | 0.7067° |
| table40 | 40 | 1294 | 0.6024° | 1.7010° | 0.6827° |
| table50 | 50 | 1295 | 0.6338° | 1.6720° | 0.7092° |

Same shape as every other unit — `linear2` clearly worst, table models
cluster with diminishing returns past ~10-20 points — but every number
runs noticeably higher than `type1_unit1`'s (table models ~0.60-0.66°
here vs. ~0.29-0.39° there). Cross-checked against the MATLAB
toolkit's own slope analysis (see below): `type3_unit1`'s calibration
curve has real, measurable waviness — RMS deviation from a straight
line 0.854° vs. `type1_unit1`'s 0.595° — so even the table models have
a less-linear curve to fit against. Second completed unit of the
planned 8-unit study; 6 remain.

## MATLAB analysis toolkit (2026-08-18/19)

`MATLAB/` — a standalone visualization toolkit for the study's own
output, built alongside the data collection itself. Not previously
written up here despite existing since 2026-08-18; this is that
write-up, folded in with the refinements made the following day.

`setup.m` forces itself and `../data` onto the path, then parses every
`study_range.py` CSV into one `MotorTypeData` object per motor type
actually present on disk — type/unit counts discovered from filenames,
never hardcoded, so it automatically picks up new units as the study
progresses (and stays correct if a unit was studied more than once —
most recent stamp wins, since a rerun supersedes an earlier
partial/smoke run and different stamps sit on different, incomparable
position references). Every `*angle_deg` column across every table is
normalized once, here, so the identified min-pulse edge sits at 0° for
every downstream script automatically. `motorTypeNames.m` is a small
lookup mirroring `MOTOR_TYPES.md`'s inventory (type number -> physical
model name); `setup.m` resolves it onto each unit, and every plot now
names units by their actual model ("Miuzei 25kg Servo Unit 2"), never
bare "type1 unit2" — "Type `<N>`" only survives as a last-resort
fallback for a type with no lookup entry.

Four standalone plotting scripts, each calling `setup()` itself:

- `plotHardStops.m` — naive/coarse/fine range-finding overlay per
  unit, min/max edges marked with leader-lined callout labels. Drops a
  sweep's first-point outlier and any non-monotonic tail generically
  (not per-unit/type) — real artifacts caught investigating this
  session's `type1_unit1`/`type3_unit1` data: a stall-recovery backoff
  and a one-off stale first reading, both logged rather than silently
  discarded.
- `plotCalibration.m` — up/down/average fine sweep with hysteresis
  shading, a Savitzky-Golay-smoothed local-slope panel (raw
  point-to-point differentiation was too noisy from AS5600 quantization
  to show real bowing), and a zoomed view of the hysteresis band over a
  fixed window anchored at each unit's own min pulse (the real band is
  too thin to see at full-range scale).
- `plotAccuracy.m` — per-trial error distribution (`boxchart`) plus
  mean/RMS/max summary statistics per model.
- `plotErrorVsAngle.m` — mean |error| by target-angle decile per
  model, showing *where* in the range each model is worst rather than
  only its aggregate error; caught real non-monotonic error patterns
  (not a simple one-directional bow) that line up with the slope
  panel's own waviness findings.

Every legend uses `eastoutside`, not `best` — `best` let a legend box
sit directly over a real trace once actual data (the error-vs-angle
plot's `linear2` peak) made the axes large enough for that overlap to
happen. Within one type's figure, every unit's axes now share
identical scale via a shared `syncAxes()` helper (synced per-row where
rows carry different measurements, e.g. calibration's curve/slope/zoom)
so units are directly visually comparable instead of each silently
auto-scaling to its own range.

## `ABS_CEIL_US` silently capped every unit's max pulse in the whole study (2026-08-25)

Real bug, found by cross-checking against a third, independent tool
(`Servo_Test.ino`, a minimal standalone sketch outside this repo) on
the same bench servo: `find_range()` and `ServoCalibrator_Companion`'s
own `CAL` both reported a max edge around 2070–2085µs, while
`Servo_Test.ino` found a real edge at 2670µs on the identical hardware.
First guess (the shared rate-based edge detection, `scan_until_weak()`,
being too conservative) didn't survive testing —
`CAL_WEAKENING_FRACTION` at 0.10 instead of 0.35 barely moved the
result (2085µs), which was the real clue: the servo's *actual* commanded
position had stopped changing at all past ~2076µs, no matter what
larger pulse was written.

Root cause: `ABS_CEIL_US` (`servo_daq.py` and `ServoDAQ_Companion.ino`
both had it at `3100`) gets passed straight to `Servo::attach()`, which
encodes the ceiling internally as `(MAX_PULSE_WIDTH - max)/4` in a
**signed `int8_t`** (`Servo.h`: `MAX_PULSE_WIDTH` 2400) — `(2400-3100)/4
= -175` doesn't fit in `int8_t` and silently wraps to 81, giving an
*actual* enforced ceiling of `2400 - 81*4 = 2076µs`. Every commanded
pulse above ~2076µs was silently rewritten to 2076µs the whole time —
indistinguishable from a genuine stall, which is exactly what
`find_range()` dutifully (and correctly, given the input it was
actually receiving) reported. `Servo_Test.ino` never hit this because
its own author had already worked out the library's real representable
max (2912µs) and capped itself there deliberately.

**This bug was live for the entire 9-unit study.** Looking back at
every unit's reported max pulse (see the top-level `CLAUDE.md`'s 9-unit
table): every single one clusters at 2065–2080µs regardless of servo
family or gear ratio — not what nine independent mechanical limits
should look like. That lines up exactly with users having reported
type1/type3 (rated ~270°) consistently measuring short of spec, and
type2 (rated ~180°) measuring short too.

**Fixed**: `ABS_CEIL_US` changed from 3100 to 2912 in both
`ServoDAQ_Companion.ino` and `servo_daq.py` (kept in sync by hand per
`servo_daq.py`'s own docstring), and identically in
`ServoCalibrator_Companion.ino` (a separate tool in this repo with the
same bug — see the main `CLAUDE.md`). `CAL_WEAKENING_FRACTION` was
reverted to its original 0.35; it was never the problem.

**Verified on two units so far**, both on real hardware:
- `type1_unit3` (Miuzei 25kg Servo): 325–2075µs (236.2°) →
  **325–2655µs (313.1°)**. A full 3h re-run (5970 trials) on the
  corrected range found the same qualitative result as before the fix —
  `linear2` still clearly worst (now by an even larger margin, since a
  straight line fits worse over a wider real range), table models still
  cluster with diminishing returns past ~10–20 points.
- `type3_unit3` (MG90D): 340–2075µs (229.8°) → **305–2620µs (308.2°)**
  (smoke-tested only so far, 637 trials, same shape).

**Not yet done**: re-running the other 7 units. Every range/stroke
number in `CLAUDE.md`'s 9-unit table, and `website/data.md`'s per-unit
charts, still reflect the pre-fix, capped measurements except for
`type1_unit3`'s range-finding chart (corrected as of this entry — see
`website/data.md`'s own top-of-page caveat). The study's central,
qualitative conclusion — an N-point table beats the naive 2-point
linear formula, with rapidly diminishing returns past ~10–20 points —
held up on both re-verified units under the real, wider range; only the
absolute range/stroke numbers were wrong.

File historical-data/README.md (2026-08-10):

# Historical data

Raw measurement CSVs from the hand-built characterization project
(`Servo_Auto_Calibrator`) that both tools in this repo grew out of —
archived here when that project's local sketchbook folder was cleaned up
(2026-08-09), since this data isn't reproduced anywhere else. Kept for
reference/reproducibility, not consumed by either tool at runtime.

- **`calibration_data.csv`** — per-step (pulse_us, angle_deg, valid) from
  the original stall-detected endpoint/linearity sweep. Confirmed this
  servo's real mechanical range and quantified how close its pulse↔angle
  response is to a straight line in each direction.
- **`hysteresis_data.csv`** — per-pulse (direction, pulse_us, angle_deg,
  valid) from a same-range up/down sweep, isolating direction-dependent
  backlash from the angle-dependent nonlinearity the calibration sweep
  found (they're confounded if measured together — see below).
- **`repeatability_data.csv`** — 140-trial single-target positioning
  results (compensated vs. uncompensated), the follow-up test that asked
  whether the measured backlash actually matters for real point-to-point
  moves, and whether a simple undershoot-and-reapproach compensation
  scheme helps.

This data — and the servo it came from — is what the calibration lookup
table both tools now use was validated against: the same nonlinearity
characterized here (~3.6–3.8° max deviation from a 2-point line) is what
led to the 20-point lookup table both `ServoCalibrator.html`'s wizard
output and `TrajectoryDemo.html`'s live comparison are built around. See
the main [`CLAUDE.md`](../CLAUDE.md) for how that investigation connects
to what's actually in this repo today.

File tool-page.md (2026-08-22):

---
title: "Servo Calibrator"
description: "A one-button browser tool that finds a hobby servo's real pulse range and builds a 20-point calibration table, using an AS5600 magnetic encoder as ground truth."
draft: true
---

Every hobby servo ships with the same assumption baked into every tutorial: pick a minimum pulse, a maximum pulse, draw a straight line between them. [It's quietly wrong](/articles/hobby-servo-calibration/) — the real pulse-to-angle curve bows away from that line, sometimes by several degrees. Servo Calibrator is the tool that measures your own servo's real curve instead of assuming one.

Wire up an Arduino Nano, an AS5600 magnetic encoder, and the servo you want to characterize; open one self-contained HTML page in the browser; click **Calibrate**. The firmware stall-scans both directions to find the servo's true mechanical limits, sweeps the full range twice, and builds a direction-averaged 20-point lookup table — no protractor, no hand measurement, usually done in under a minute. Once calibrated, the same page drives and plots a live trajectory against that table, with a toggle to compare it against the naive 2-point line in real time.

This tool is purely for characterization — it doesn't ask about horn position, direction, or a logical zero point, and it always reports the servo's own physical range, `[0, maxAngle]`. Turning that into an actual motor-driver constructor for your project is a separate, application-specific step.

## Wiring

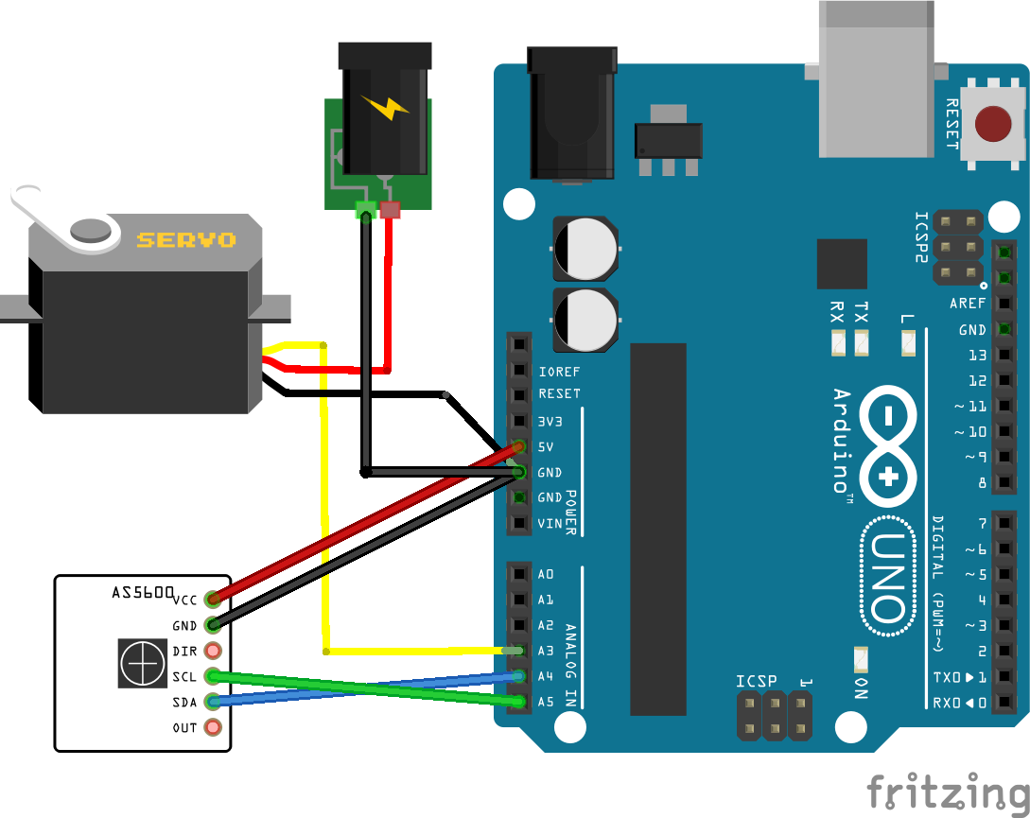
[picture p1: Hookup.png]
Fritzing wiring diagram showing an Arduino Nano connected to an AS5600 magnetic encoder over I2C and to a servo's signal line, with the servo powered from a separate external supply.


The AS5600 never touches the servo — it's a contactless magnetic angle sensor that just watches a magnet spin underneath it. That means the one physical requirement is a **diametrically magnetized** magnet (poles across the diameter, not the faces) mounted on the servo's output shaft, centered over the chip, a millimeter or two above the package. I didn't build any special mount for mine — just glued the magnet onto a spare servo horn and bolted the horn back on.

Everything else is ordinary wiring: servo signal to a digital pin (`A3` in the stock firmware), AS5600 on the board's I²C bus (`SDA`/`SCL` — `A4`/`A5` on an Uno/Nano), common ground tying the Arduino, the AS5600, and the servo together.

The one thing worth getting right is power. **Run the servo off its own external 4.8&ndash;6V supply, not the Arduino's 5V or Vin pin** — a small board's onboard regulator generally can't source a servo's stall current. 4.8&ndash;6V covers most hobby servos, but check your particular servo's datasheet before wiring it up; some digital servos want a narrower or higher range. Either way, tie that supply's ground to the Arduino's ground, or both the encoder readings and the servo's behavior get unreliable.

## Getting it running

1. **Install two libraries in the Arduino IDE** — both free, no private access needed:
   - **`AS5600`** (RobTillaart's) via Library Manager (`Sketch → Include Library → Manage Libraries…`, search `AS5600`), or `arduino-cli lib install "AS5600"`.
   - **[Universal-Trajectory-Interface](https://github.com/vishwam-aggarwal/Universal-Trajectory-Interface)** — not in Library Manager's index, so install it manually: download the repo as a ZIP from GitHub and use `Sketch → Include Library → Add .ZIP Library…`, or `git clone` it straight into your sketchbook's `libraries/` folder. Restart the IDE if it was already open.
2. **Flash the firmware.** Open `ServoCalibrator_Companion/ServoCalibrator_Companion.ino` from the [GitHub repo](https://github.com/vishwam-aggarwal/Servo-Calibrator) in the Arduino IDE and upload it to your board, same as any other sketch. Servo signal is fixed at pin `A3` in the sketch (edit `SERVO_PIN` if you need a different one).
3. **Serve the app.** `ServoCalibrator.html` needs `http://`, not a `file://` URL, for Web Serial to work reliably — `python -m http.server 8000` from the folder it's in, then open it in **Chrome or Edge** (Web Serial isn't implemented in Firefox or Safari).
4. **Connect, then Calibrate.** Click *Connect…*, pick your board's serial port, then click **Calibrate**. One button, fully automated — the trajectory/chart interface unlocks once the sweep finishes.

Full protocol reference, safety notes, and known limitations are in the [project README](https://github.com/vishwam-aggarwal/Servo-Calibrator).

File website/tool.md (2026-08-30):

---
title: "Servo Calibrator"
description: "A one-button browser tool that finds a hobby servo's real pulse range and builds a 20-point calibration table, using an AS5600 magnetic encoder as ground truth."
tags: ["Web Serial", "Robotics", "Arduino"]
status: active
repo: "https://github.com/vishwam-aggarwal/Servo-Calibrator"
draft: false
---

Every hobby servo ships with the same assumption baked into every tutorial: pick a minimum pulse, a maximum pulse, draw a straight line between them. [It's quietly wrong](/articles/hobby-servo-calibration/) — the real pulse-to-angle curve bows away from that line, sometimes by several degrees. Servo Calibrator is the tool that measures your own servo's real curve instead of assuming one.

Wire up any Arduino with I²C and a PWM-capable pin, an AS5600 magnetic encoder, and the servo you want to characterize; open one self-contained HTML page in the browser; click **Calibrate**. The firmware stall-scans both directions to find the servo's true mechanical limits, sweeps the full range twice, and builds a direction-averaged 20-point lookup table — no protractor, no hand measurement, usually done in under a minute. Once calibrated, the same page drives and plots a live trajectory against that table, with a toggle to compare it against the naive 2-point line in real time.

This tool is purely for characterization — it doesn't ask about horn position, direction, or a logical zero point, and it always reports the servo's own physical range, `[0, maxAngle]`. Turning that into an actual motor-driver constructor for your project is a separate, application-specific step.

## Wiring

Fritzing wiring diagram showing an Arduino Nano connected to an AS5600 magnetic encoder over I2C and to a servo's signal line, with the servo powered from a separate external supply.

The AS5600 never touches the servo — it's a contactless magnetic angle sensor that just watches a magnet spin underneath it. That means the one physical requirement is a **diametrically magnetized** magnet (poles across the diameter, not the faces) mounted on the servo's output shaft, centered over the chip, a millimeter or two above the package. I didn't build any special mount for mine — just glued the magnet onto a spare servo horn and bolted the horn back on.

Everything else is ordinary wiring: servo signal to a digital pin (`A3` in the stock firmware), AS5600 on the board's I²C bus (`SDA`/`SCL` — `A4`/`A5` on an Uno/Nano), common ground tying the Arduino, the AS5600, and the servo together.

The one thing worth getting right is power. **Run the servo off its own external 4.8&ndash;6V supply, not the Arduino's 5V or Vin pin** — a small board's onboard regulator generally can't source a servo's stall current. 4.8&ndash;6V covers most hobby servos, but check your particular servo's datasheet before wiring it up; some digital servos want a narrower or higher range. Either way, tie that supply's ground to the Arduino's ground, or both the encoder readings and the servo's behavior get unreliable.

## Getting the firmware to compile

The sketch needs four libraries that don't ship with the Arduino IDE — one third-party, three of mine — so a fresh install needs a few extra steps before `ServoCalibrator_Companion.ino` will build:

1. **Install AS5600** (RobTillaart's) — it's in the Library Manager's index, so `Sketch → Include Library → Manage Libraries…`, search `AS5600`, install the one by RobTillaart. Or from the command line: `arduino-cli lib install "AS5600"`. The firmware talks to it through Universal-Encoder-Interface rather than directly, but that's a wrapper around this library, not a replacement for it.
2. **Add Universal-Encoder-Interface as a library** — same two options as the next step. It provides `AS5600EncoderDriver`, which handles reading the encoder across full revolutions without the angle wrapping back to zero every turn.
3. **Add Universal-Trajectory-Interface as a library** — this is the step that trips people up, since it isn't in Library Manager's index. Either:
   - Download the [Universal-Trajectory-Interface repo](https://github.com/vishwam-aggarwal/Universal-Trajectory-Interface) as a ZIP (`Code → Download ZIP`) and use `Sketch → Include Library → Add .ZIP Library…`, pointing at that ZIP — the IDE unpacks it into your sketchbook's `libraries/` folder itself; or
   - `git clone` it straight into your sketchbook's `libraries/` folder, e.g. `~/Documents/Arduino/libraries/Universal-Trajectory-Interface` — no rename needed, it already ships a proper `library.properties`.
4. **Add Universal-Device-Interface as a library too** — same two options, same place. The sketch never includes anything from it directly; it's the shared base the two libraries above are both built on, and the IDE compiles every source file in a library whether your sketch uses it or not. Skip this and the build stops at `fatal error: IDevice.h: No such file or directory`, which is confusing precisely because nothing you wrote asked for that file.

   Restart the IDE afterward if it was already open, so it picks up the new libraries.
5. **Flash the firmware.** Open `ServoCalibrator_Companion/ServoCalibrator_Companion.ino` from the [GitHub repo](https://github.com/vishwam-aggarwal/Servo-Calibrator) in the Arduino IDE and upload it to your board, same as any other sketch. Servo signal is fixed at pin `A3` in the sketch (edit `SERVO_PIN` if you need a different one).

All four libraries are free and public — no private access or account needed for any of them.

## Using the tool

Once the firmware's flashed and the board's wired up per the diagram above, click **Launch Servo Calibrator** below, then **Connect…** and pick your board's serial port. Click **Calibrate** — one button, fully automated — and the trajectory/chart interface unlocks once the sweep finishes.

Full protocol reference, safety notes, and known limitations are in the [project README](https://github.com/vishwam-aggarwal/Servo-Calibrator).

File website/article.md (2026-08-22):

---
title: "Your Servo Is Lying To You"
description: "Nine hobby servos, 55,000 measured moves, and the calibration trick that turns a wobbly robotic arm into a precise one."
pubDate: 2026-08-21
tags: ["Robotics", "Embedded", "Control Theory"]
draft: false
---

I wanted to build the best robotic arm I could out of hobby servos — no exotic actuators, no $400 Dynamixels, just the same $8–$25 servos everyone already has a drawer full of. The bottleneck turned out not to be torque, or speed, or even the servos themselves. It was math.

Every hobby-servo project I'd seen — including my own earlier one, [Servo Calibrator](/projects/servo-calibrator/) — points the shaft with the same two numbers: a minimum pulse width, a maximum pulse width, and a straight line drawn between them. Command 90°, get roughly 1500µs; command 45°, get roughly 1125µs. It's the formula in every tutorial, every library, every datasheet's "quick start." It's also, it turns out, quietly wrong — and the wrongness isn't random. It's a real, measurable, servo-specific curve that a straight line simply can't capture.

So I built a bench rig — an Arduino, an AS5600 magnetic encoder riding on the output shaft as ground truth, and a Python driver that could sweep, measure, and grade any servo I threw at it — and set out to answer one question with actual data, not vibes: **how much accuracy is that straight line actually costing me, and is it worth fixing?**

The fix itself isn't exotic — it's a lookup table. Instead of one straight line from min-pulse to max-pulse, sweep the real servo across its full range, record the actual angle at a bunch of pulse widths, and interpolate between the two nearest real measurements instead of trusting a formula. This obviously works in principle. What I wanted to know was how much it's worth, in real degrees, on real hardware, across more than one servo — because a result from a single unit could just be that unit having a bad day.

## The bench

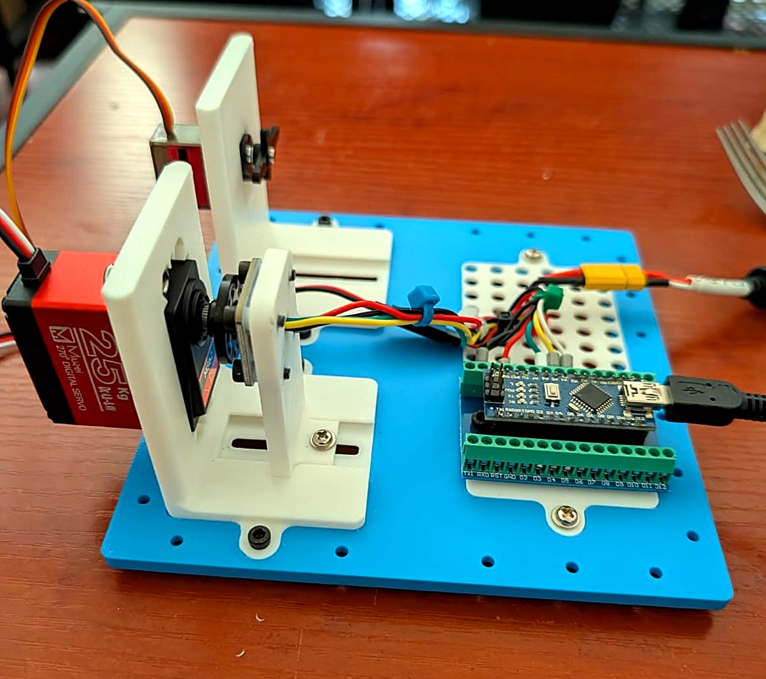
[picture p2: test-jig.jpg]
The physical test jig: a Miuzei 25kg Servo (left, red) with the AS5600 magnetic encoder mounted directly on its output shaft, and an MG90D (right), both bolted to a 3D-printed bracket, wired to an Arduino Nano clone on a screw-terminal breakout.


*The actual rig, one unit at a time: a Miuzei 25kg Servo with the AS5600 mounted on it on the left, an MG90D on the right, an Arduino Nano (CH340 clone) doing the driving.*

Nine servos, three families — a Miuzei 25kg Servo, a knockoff MG996R, and an MG90D, three units each — went through the same protocol: a direction-averaged fine sweep against the AS5600 as ground truth, then thousands of independent accuracy trials. Every trial picked a random target angle *and* a random model independently, computed that model's predicted pulse, physically commanded it, waited a full second, and measured the real resulting angle. Target and model are drawn independently on purpose — an earlier pass through this data paired them, and it quietly let a bad model borrow a good model's positioning within the same round. Decoupling them was the difference between a flattering result and a true one.

55,029 independent trials, six models compared per servo (the naive 2-point linear formula, plus 10/20/30/40/50-point lookup tables), across every unit — not a residual against the calibration curve that produced the table in the first place.

Everything below is the pooled, family-level view. If you want the unabridged version — every unit's own range-finding sweep, calibration curve, backlash, and accuracy, not averaged together — the [full dataset](/articles/hobby-servo-calibration/data) has all of it.

<div class="chart-figure">
<p class="chart-title">Mean error vs. model complexity, pooled across all nine servos</p>
<svg viewBox="0 0 680 260" role="img" aria-label="Line chart showing mean absolute error dropping sharply from the naive linear model at 1.33 degrees to a 10-point table at 0.43 degrees, then staying nearly flat through a 50-point table at 0.41 degrees">
<g stroke="var(--border)" stroke-width="1">
<line x1="48" y1="220" x2="656" y2="220" />
<line x1="48" y1="153.3" x2="656" y2="153.3" />
<line x1="48" y1="86.7" x2="656" y2="86.7" />
<line x1="48" y1="20" x2="656" y2="20" />
</g>
<g font-family="var(--font-mono)" font-size="11" fill="var(--text-faint)" text-anchor="end">
<text x="40" y="224">0.0&#176;</text>
<text x="40" y="157.3">0.5&#176;</text>
<text x="40" y="90.7">1.0&#176;</text>
<text x="40" y="24">1.5&#176;</text>
</g>
<g font-family="var(--font-mono)" font-size="11" fill="var(--text-faint)" text-anchor="middle">
<text x="48" y="240">linear2</text>
<text x="169.6" y="240">table10</text>
<text x="291.2" y="240">table20</text>
<text x="412.8" y="240">table30</text>
<text x="534.4" y="240">table40</text>
<text x="656" y="240">table50</text>
</g>
<line x1="48" y1="42.7" x2="169.6" y2="162.3" stroke="var(--series-2)" stroke-width="2" stroke-dasharray="6 4"/>
<path d="M 169.6 162.3 L 291.2 162.9 L 412.8 164.1 L 534.4 164.5 L 656 165.1" fill="none" stroke="var(--series-1)" stroke-width="2.5" stroke-linecap="round" stroke-linejoin="round"/>
<circle cx="48" cy="42.7" r="5" fill="var(--bg-raised)" stroke="var(--series-2)" stroke-width="2.5"/>
<text x="48" y="30.7" font-size="11" fill="var(--text)" font-weight="600" text-anchor="middle">1.33&#176;</text>
<circle cx="169.6" cy="162.3" r="4" fill="var(--bg-raised)" stroke="var(--series-1)" stroke-width="2.5"/>
<text x="169.6" y="150.3" font-size="11" fill="var(--text)" font-weight="600" text-anchor="middle">0.43&#176;</text>
<circle cx="291.2" cy="162.9" r="4" fill="var(--bg-raised)" stroke="var(--series-1)" stroke-width="2.5"/>
<circle cx="412.8" cy="164.1" r="4" fill="var(--bg-raised)" stroke="var(--series-1)" stroke-width="2.5"/>
<circle cx="534.4" cy="164.5" r="4" fill="var(--bg-raised)" stroke="var(--series-1)" stroke-width="2.5"/>
<circle cx="656" cy="165.1" r="4" fill="var(--bg-raised)" stroke="var(--series-1)" stroke-width="2.5"/>
<text x="656" y="153.1" font-size="11" fill="var(--text)" font-weight="600" text-anchor="middle">0.41&#176;</text>
</svg>
<div class="chart-legend">
<span><span class="swatch" style="background: var(--series-1);"></span>Calibration table (10&ndash;50 points)</span>
<span><span class="swatch" style="background: var(--series-2);"></span>Naive 2-point linear model</span>
</div>
<p class="chart-caption">Grand mean absolute error across all nine units, six models, 55,029 independent physically-measured trials.</p>
</div>

The cliff happens once, between the naive formula and the first real table. After that, the line is flat — `table50` is within noise of `table10`, on every family, every time. If you're storing this on an ATmega with 2KB of RAM, that's good news: you don't need fifty points of precision to get fifty points' worth of accuracy. Ten to twenty is the whole win.

## The penalty isn't the same for every servo

Averaged per family, the naive formula's mean error is 0.87° for the Miuzei 25kg Servo, 1.16° for the knockoff MG996R, and **1.97°** for the MG90D — more than double the Miuzei's. The MG90D's calibration curve simply bows further from a straight line than the other two designs do; on one individual unit its naive error hit 2.75°. For that servo, a lookup table isn't optional insurance — it's the difference between a servo that behaves linearly and one that doesn't.

| Family | Naive (linear2) | Calibrated (table20) | Backlash (mean) | Lost in testing |
|---|---|---|---|---|
| Miuzei 25kg Servo | 0.87° | 0.40° | 1.17° | 0 of 3 |
| Knockoff MG996R | 1.16° | 0.31° | 1.03° | 2 of 3 |
| MG90D | 1.97° | 0.57° | 1.33° | 0 of 3 |

The knockoff MG996R deserves its own aside: once calibrated, its accuracy is the best of the three families (as low as 0.18° on one unit) — but two different physical units died mid-study, both from encoder-freeze failures that took the motor with them. The study's original plan was even an 8-hour accuracy phase; the very first candidate tested — a knockoff MG996R — died about 3.5 hours in, which is why every unit after it ran a 3-hour standard instead, and a second knockoff MG996R later died 61 minutes into *that* standard, which is why this family alone now runs on a 1-hour cap. If you build with these: budget for spares.

## The servos aren't built the same, mechanically

Accuracy wasn't the only thing this bench measured. Every unit's full range-finding sweep and fine calibration sweep also produced two more numbers worth knowing before you design around one of these: how much pulse width actually buys you a degree of rotation, and how much backlash — the gap between approaching an angle from above versus below — a static calibration table can't touch at all.

<div class="chart-figure">
<p class="chart-title">Pulse width required per degree of rotation, by family</p>
<svg viewBox="0 0 680 260" role="img" aria-label="Bar chart showing the knockoff MG996R needs 10.8 microseconds of pulse width per degree of rotation, versus 7.4 for the Miuzei 25kg Servo and 7.5 for the MG90D">
<line x1="48" y1="216.0" x2="656" y2="216.0" stroke="var(--border)" stroke-width="1"/>
<text x="40" y="220.0" font-family="var(--font-mono)" font-size="11" fill="var(--text-faint)" text-anchor="end">0</text>
<line x1="48" y1="167.0" x2="656" y2="167.0" stroke="var(--border)" stroke-width="1"/>
<text x="40" y="171.0" font-family="var(--font-mono)" font-size="11" fill="var(--text-faint)" text-anchor="end">3</text>
<line x1="48" y1="118.0" x2="656" y2="118.0" stroke="var(--border)" stroke-width="1"/>
<text x="40" y="122.0" font-family="var(--font-mono)" font-size="11" fill="var(--text-faint)" text-anchor="end">6</text>
<line x1="48" y1="69.0" x2="656" y2="69.0" stroke="var(--border)" stroke-width="1"/>
<text x="40" y="73.0" font-family="var(--font-mono)" font-size="11" fill="var(--text-faint)" text-anchor="end">10</text>
<line x1="48" y1="20.0" x2="656" y2="20.0" stroke="var(--border)" stroke-width="1"/>
<text x="40" y="24.0" font-family="var(--font-mono)" font-size="11" fill="var(--text-faint)" text-anchor="end">13</text>
<rect x="94.3" y="104.4" width="110" height="111.6" fill="var(--series-1)"/>
<text x="149.3" y="94.4" font-family="var(--font-mono)" font-size="12" fill="var(--text)" font-weight="600" text-anchor="middle">7.4 &#181;s/&#176;</text>
<text x="149.3" y="236" font-family="var(--font-mono)" font-size="11" fill="var(--text-faint)" text-anchor="middle">Miuzei 25kg Servo</text>
<rect x="297.0" y="53.2" width="110" height="162.8" fill="var(--series-1)"/>
<text x="352.0" y="43.2" font-family="var(--font-mono)" font-size="12" fill="var(--text)" font-weight="600" text-anchor="middle">10.8 &#181;s/&#176;</text>
<text x="352.0" y="236" font-family="var(--font-mono)" font-size="11" fill="var(--text-faint)" text-anchor="middle">Knockoff MG996R</text>
<rect x="499.7" y="102.9" width="110" height="113.1" fill="var(--series-1)"/>
<text x="554.7" y="92.9" font-family="var(--font-mono)" font-size="12" fill="var(--text)" font-weight="600" text-anchor="middle">7.5 &#181;s/&#176;</text>
<text x="554.7" y="236" font-family="var(--font-mono)" font-size="11" fill="var(--text-faint)" text-anchor="middle">MG90D</text>
</svg>
<p class="chart-caption">All nine units were swept across a similar ~1.6&ndash;1.8ms pulse span. The knockoff MG996R needs ~46% more of it per degree of real rotation than the other two families &mdash; a real gearing difference, consistent across all three of its own units, not a calibration artifact.</p>
</div>

The gearing difference matters for planning a build (a narrower pulse span buys less usable range on the MG996R), but it's a separate question from backlash — the up-sweep and down-sweep of the same fine calibration disagreeing at the same commanded pulse, purely from mechanical slop in the gear train. A lookup table stores one angle per pulse; it has no way to represent "depends which direction you came from," and can't fix this even in principle.

<div class="chart-figure">
<p class="chart-title">Backlash: mean vs. worst-case disagreement, by family</p>
<svg viewBox="0 0 680 290" role="img" aria-label="Grouped bar chart of mean and maximum backlash by servo family. The MG90D has both the highest mean backlash at 1.33 degrees and the highest worst-case backlash at 2.93 degrees">
<line x1="48" y1="246.0" x2="656" y2="246.0" stroke="var(--border)" stroke-width="1"/>
<text x="40" y="250.0" font-family="var(--font-mono)" font-size="11" fill="var(--text-faint)" text-anchor="end">0.0</text>
<line x1="48" y1="189.5" x2="656" y2="189.5" stroke="var(--border)" stroke-width="1"/>
<text x="40" y="193.5" font-family="var(--font-mono)" font-size="11" fill="var(--text-faint)" text-anchor="end">0.8</text>
<line x1="48" y1="133.0" x2="656" y2="133.0" stroke="var(--border)" stroke-width="1"/>
<text x="40" y="137.0" font-family="var(--font-mono)" font-size="11" fill="var(--text-faint)" text-anchor="end">1.6</text>
<line x1="48" y1="76.5" x2="656" y2="76.5" stroke="var(--border)" stroke-width="1"/>
<text x="40" y="80.5" font-family="var(--font-mono)" font-size="11" fill="var(--text-faint)" text-anchor="end">2.5</text>
<line x1="48" y1="20.0" x2="656" y2="20.0" stroke="var(--border)" stroke-width="1"/>
<text x="40" y="24.0" font-family="var(--font-mono)" font-size="11" fill="var(--text-faint)" text-anchor="end">3.3</text>
<rect x="101.3" y="165.9" width="44" height="80.1" fill="var(--series-1)"/>
<text x="123.3" y="157.9" font-family="var(--font-mono)" font-size="10.5" fill="var(--text)" text-anchor="middle">1.17&#176;</text>
<rect x="153.3" y="101.5" width="44" height="144.5" fill="var(--series-2)"/>
<text x="175.3" y="93.5" font-family="var(--font-mono)" font-size="10.5" fill="var(--text)" text-anchor="middle">2.11&#176;</text>
<text x="149.3" y="266" font-family="var(--font-mono)" font-size="11" fill="var(--text-faint)" text-anchor="middle">Miuzei 25kg Servo</text>
<rect x="304.0" y="175.5" width="44" height="70.5" fill="var(--series-1)"/>
<text x="326.0" y="167.5" font-family="var(--font-mono)" font-size="10.5" fill="var(--text)" text-anchor="middle">1.03&#176;</text>
<rect x="356.0" y="120.0" width="44" height="126.0" fill="var(--series-2)"/>
<text x="378.0" y="112.0" font-family="var(--font-mono)" font-size="10.5" fill="var(--text)" text-anchor="middle">1.84&#176;</text>
<text x="352.0" y="266" font-family="var(--font-mono)" font-size="11" fill="var(--text-faint)" text-anchor="middle">Knockoff MG996R</text>
<rect x="506.7" y="154.9" width="44" height="91.1" fill="var(--series-1)"/>
<text x="528.7" y="146.9" font-family="var(--font-mono)" font-size="10.5" fill="var(--text)" text-anchor="middle">1.33&#176;</text>
<rect x="558.7" y="45.3" width="44" height="200.7" fill="var(--series-2)"/>
<text x="580.7" y="37.3" font-family="var(--font-mono)" font-size="10.5" fill="var(--text)" text-anchor="middle">2.93&#176;</text>
<text x="554.7" y="266" font-family="var(--font-mono)" font-size="11" fill="var(--text-faint)" text-anchor="middle">MG90D</text>
</svg>
<div class="chart-legend">
<span><span class="swatch" style="background: var(--series-1);"></span>Mean backlash</span>
<span><span class="swatch" style="background: var(--series-2);"></span>Worst-case (max) backlash</span>
</div>
<p class="chart-caption">Up-sweep vs. down-sweep disagreement at shared pulse values, from the same fine calibration sweep that built each unit's ground truth. The MG90D&mdash;already the servo whose curve bows furthest from a straight line&mdash;also has the most backlash, on average and at its worst.</p>
</div>

It's not a coincidence that the MG90D leads both charts in this section as well as the accuracy table above it: whatever makes its mechanism less linear also tends to make it looser. None of that shows up in a lookup table's numbers directly, but it's exactly the kind of thing a table can't fix — if a build's joints need to settle to a repeatable position regardless of approach direction, that's a mechanical design problem (a hard stop, a spring preload, a consistent single approach direction in software), not a calibration one.

## Why a single joint can shrug off a degree, and an arm can't

A pan/tilt camera mount can absorb a degree of error and nobody notices the horizon tilt. A robotic arm can't — every joint's error doesn't just sit there, it rides on top of every joint downstream of it, compounding into wherever the end effector actually lands.

<div class="chart-figure">
<p class="chart-title">End-effector drift radius: naive linear model vs. calibrated table, three-joint arm</p>
<svg viewBox="0 0 850 340" role="img" aria-label="Diagram of a three-joint arm with two circles at the end effector showing positional drift radius, roughly 8.4 millimeter radius for the naive linear model versus 2.7 millimeter radius for a calibrated table">
<rect x="40" y="290" width="64" height="15" fill="var(--bg-raised)" stroke="var(--border)" stroke-width="1.5"/>
<circle cx="72" cy="282" r="13" fill="var(--bg-raised)" stroke="var(--accent)" stroke-width="2.5"/>
<line x1="72" y1="282" x2="300" y2="210" stroke="var(--text-faint)" stroke-width="2.5"/>
<text x="186" y="238" font-family="var(--font-mono)" font-size="12.5" fill="var(--text-faint)" text-anchor="middle">120mm</text>
<circle cx="300" cy="210" r="11" fill="var(--bg-raised)" stroke="var(--accent)" stroke-width="2.5"/>
<line x1="300" y1="210" x2="500" y2="150" stroke="var(--text-faint)" stroke-width="2.5"/>
<text x="400" y="172" font-family="var(--font-mono)" font-size="12.5" fill="var(--text-faint)" text-anchor="middle">120mm</text>
<circle cx="500" cy="150" r="10" fill="var(--bg-raised)" stroke="var(--accent)" stroke-width="2.5"/>
<line x1="500" y1="150" x2="630" y2="108" stroke="var(--text-faint)" stroke-width="2.5"/>
<text x="565" y="121" font-family="var(--font-mono)" font-size="12.5" fill="var(--text-faint)" text-anchor="middle">120mm</text>
<circle cx="630" cy="108" r="52" fill="none" stroke="var(--series-2)" stroke-width="2.5" stroke-dasharray="6 5"/>
<circle cx="630" cy="108" r="20" fill="none" stroke="var(--series-1)" stroke-width="3"/>
<circle cx="630" cy="108" r="3.5" fill="var(--text)"/>
<line x1="630" y1="108" x2="677.5" y2="86.8" stroke="var(--series-2)" stroke-width="1.75"/>
<line x1="677.5" y1="86.8" x2="700" y2="58" stroke="var(--border)" stroke-width="1" stroke-dasharray="3 3"/>
<text x="706" y="56" font-family="var(--font-mono)" font-size="13" fill="var(--series-2)" text-anchor="start">radius &#8776; 8.4mm</text>
<text x="706" y="73" font-family="var(--font-mono)" font-size="11" fill="var(--text-faint)" text-anchor="start">linear2</text>
<line x1="630" y1="108" x2="649.4" y2="103.2" stroke="var(--series-1)" stroke-width="1.75"/>
<line x1="649.4" y1="103.2" x2="700" y2="140" stroke="var(--border)" stroke-width="1" stroke-dasharray="3 3"/>
<text x="706" y="138" font-family="var(--font-mono)" font-size="13" fill="var(--series-1)" text-anchor="start">radius &#8776; 2.7mm</text>
<text x="706" y="155" font-family="var(--font-mono)" font-size="11" fill="var(--text-faint)" text-anchor="start">table20</text>
</svg>
<div class="chart-legend">
<span><span class="swatch" style="background: var(--series-1);"></span>Calibrated (table20)</span>
<span><span class="swatch" style="background: var(--series-2);"></span>Naive linear model</span>
</div>
<p class="chart-caption">Three joints &times; 120mm links, this study's average angular error &mdash; order-of-magnitude estimate, not a full kinematic stack-up. Both circles show a <strong>radius</strong>, not a diameter: the distance from the commanded point to where the end effector actually lands, not the width across the uncertainty region.</p>
</div>

Take a modest three-joint arm — shoulder, elbow, wrist, each riding on a 120mm link, well within reach of servos this size. Run this study's average numbers through it: the naive straight-line formula puts roughly **2.8mm** of drift on the end effector from each joint's error, on its own. Stack three of them and a build commanded to hit an exact point can land more than **8mm** away from where you told it to go — enough to miss a socket, misplace a component, or draw a line that visibly isn't straight.

Swap in a 20-point calibration table built from the same kind of sweep this study ran, and each joint's error drops from ~1.3° to ~0.4° — cutting that same three-joint arm's drift to roughly **2.7mm**. That's the difference between an arm whose accuracy is limited by its own math, and one whose accuracy is limited by the thing that should actually be limiting it: backlash, structural flex, and how tightly it was built.

## So, what's the best arm I can build?

Bench-tested and totaled up: run through a 10-to-20-point calibration table instead of the textbook formula, the Miuzei and the knockoff MG996R both land within half a degree of their commanded target — sub-millimeter positioning on a typical hobby-arm link. The MG90D lands a little behind that, at 0.57° — just over a millimeter at the same link length — but that's still a huge jump from its naive 1.97°, just not quite sub-millimeter. Either way, that's not a marginal win worth shrugging off; it's the difference between a robot arm that reaches *roughly* where you tell it to, and one that actually lands there.

Which family to build with comes down to reach, load, and how many spares you're willing to keep on a shelf, not whether it's worth calibrating — on this bench, that was never really in question. The Miuzei is the steady, reliable default for a base or shoulder joint. The MG90D is small, cheap, and needs the table most, which makes it a strong pick for a wrist or gripper specifically because calibration erases its biggest weakness. The knockoff MG996R has the best calibrated accuracy of the three, but earned its reliability caveat honestly — keep spares.

## Calibrate your own servo

You don't need this bench to get this result on your own servo. Everything above runs through [Servo Calibrator](/tools/servo-calibrator/), a free browser tool built from this same study: wire up an AS5600 breakout and any Arduino — a few dollars in parts, nothing exotic — flash one sketch, then click a single **Calibrate** button. It stall-scans the servo's real mechanical range, sweeps it twice, and builds a direction-averaged 20-point table automatically, usually in well under a minute. No protractor, no spreadsheet, no manually stepping through pulse widths by hand.

A table alone only fixes *where* the servo ends up — it says nothing about *how* it gets there. That's a separate problem: [Universal-Trajectory-Interface](/articles/universal-trajectory-interface/), the trajectory-planning library that Servo Calibrator's own firmware already uses to drive smooth, speed-and-acceleration-limited moves against your table instead of snapping straight to the target.

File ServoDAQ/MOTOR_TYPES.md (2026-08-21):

# Motor types

Inventory numbers used in `study_range.py`'s output filenames
(`type<N>_unit<M>_<timestamp>_*.csv`) for the multi-servo characterization
study. Plain integers only, by design — no product names in filenames,
matching how the study itself doesn't care what a servo is called, only
how it actually behaves.

| Type | Model | Units |
|---|---|---|
| 1 | Miuzei 25kg Servo | 3 (unit1, unit2, unit3) |
| 2 | Knockoff MG996R | 3 (unit1, unit2, unit3) |
| 3 | MG90D | 3 (unit1, unit2, unit3) |

9 units total across 3 types, **study complete** (2026-08-21) — every
unit has a full accuracy run; see `CLAUDE.md`'s dated entry for the
final results table. Originally planned as 8 units (`type1` x2); the
user ordered a third `type1` unit specifically to give every family 3
units. `type0`/`unit0` is reserved by `study_range.py` itself for
unlabeled/test runs (smoke tests, dev runs) when `MOTOR_TYPE`/`UNIT`
aren't passed — never used for real study data.

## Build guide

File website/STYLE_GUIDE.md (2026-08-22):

# Website Style Guide

Canonical copy of this file lives here, in the `vishwamaggarwal.com` repo
(`STYLE_GUIDE.md` at repo root). Every project repo that has a `website/`
folder keeps its own copy at `website/STYLE_GUIDE.md` — same content,
copied by hand whenever this one changes (there's no automated sync).

**Who this is for**: anyone — human or Claude — writing or editing
`website/article.md`, `website/data.md`, `website/tool.md`, or
`website/app.html` in a project repo. Read this *before* writing new
website content in a project repo, so it looks and behaves consistently
with the rest of the site without needing to cross-check this repo.

If you only remember one thing: **you write semantic content (markdown,
plain HTML, inline SVG); the surrounding page chrome — nav, tag row,
status badge, buttons, back-links — comes from frontmatter and the
website repo's own page templates.** Don't hand-author chrome inside your
markdown body.

---

## 1. The `website/` folder contract

Every project repo the site pulls from keeps everything it feeds to
vishwamaggarwal.com under one `website/` folder instead of loose files at
repo root:

```
website/
  article.md     # long-form write-up (optional)
  data.md         # companion "full dataset" page (optional, needs article.md)
  tool.md         # Tools-section landing page content (optional — only if
                  #   this repo ships a browser tool)
  app.html        # the tool's actual self-contained web app (optional,
                  #   pairs with tool.md — generic filename, not
                  #   tool-specific, so every tool's app is predictably
                  #   website/app.html)
  images/
    <filename>    # images referenced by article.md/data.md/tool.md
  sources/
    <filename>    # editable source behind an image in images/ (Fritzing
                  #   .fzz, KiCad/Eagle projects, Illustrator, etc.) —
                  #   never fetched/served, pure repo hygiene, see below
  STYLE_GUIDE.md  # this file
```

Only include the files this repo actually needs — a repo with no browser
tool has no `tool.md`/`app.html`; a repo with no companion dataset has no
`data.md`; no `sources/` at all if nothing in `images/` has (or needs) an
editable source kept around.

### `sources/` — editable source files behind an image

If an image in `images/` was exported from something editable (a
Fritzing wiring diagram, a KiCad/Eagle schematic, an Illustrator file,
whatever) and you want to keep that source around for future edits, it
goes in `sources/`, named to **exactly match the exported image's
basename**, extension aside:

```
website/images/hookup.png   <->   website/sources/hookup.fzz
```

That's the entire convention — one folder, one naming rule (match the
basename), no per-tool registry to update. It works the same way
regardless of which design tool produced the source, so a future KiCad
or Illustrator file needs no new rule invented for it.

**Never referenced by `content.config.ts` and never fetched by the
website** — `sources/` is pure repo-side hygiene for whoever edits the
diagram later, not build input. Don't add a `sources/*` entry to any
loader's `images` array; there's nothing for the site to do with a raw
`.fzz` file, it can't render it.

**To register a new source**: add one entry to the relevant array
(`articleSources`, `toolPageSources`, `toolAppSources`) in the website
repo's `src/content.config.ts`. See that file's own comments for the
exact shape. This step happens in the website repo, not here — if you're
working in a project repo alone, tell the user this step is still needed
there.

---

## 2. Content types & frontmatter

Every file below is standard markdown with YAML frontmatter, parsed and
schema-validated by the website's Content Layer loader. Extra frontmatter
fields are ignored, not an error — but a missing *required* field fails
that source's fetch (logged as a build warning, non-fatal to the rest of
the site).

### `article.md`

```yaml
---
title: "Your Motor Doesn't Know How To Get There"
description: "One-sentence summary — used in <meta description>, og:description, and article list previews."
pubDate: 2026-08-22
tags: ["Robotics", "Embedded", "Motion Control"]
draft: true
---
```

- `title`, `description`, `pubDate` are required. `tags` defaults to `[]`.
- Rendered at `/articles/<id>/`, inside the site's narrow **prose** column
  (see §3) — this is continuous long-form reading content.

### `data.md` (optional companion to `article.md`)

```yaml
---
title: "Your Motor Doesn't Know How To Get There — Full Dataset"
description: "Every plot and the full dataset behind the article."
draft: true
---
```

- Rendered at `/articles/<id>/data/`. Link to it from the bottom of
  `article.md` by hand, wherever it reads naturally — it's not linked
  from anywhere else, deliberately: a page for the reader who wants more
  than the article chose to show, not a second front door into the
  content.
- Also prose-column width, but `.chart-figure` is allowed to break out
  wider on screens ≥56rem here specifically (dense multi-subplot grids
  need the room). `article.md`'s charts intentionally stay at the
  narrower text-column width — the two pages are allowed to disagree on
  this.

### `tool.md`

```yaml
---
title: "Servo Calibrator"
description: "One-sentence summary of what the tool does."
tags: ["Web Serial", "Robotics", "Arduino"]
status: active   # active | shipped | archived
repo: "https://github.com/owner/repo"
draft: true
---
```

- `title`, `description`, `repo` are required. `tags` defaults to `[]`,
  `status` defaults to `active`.
- Rendered at `/tools/<id>/` in the site's **wide** column (see §3) —
  this is a landing page, not continuous prose.
- The page template supplies the back-link, the tag row + status badge
  (from `tags`/`status`), a fixed button row (**Launch** →
  `/tools/<id>/app/`, **View on GitHub** → `repo`), and a comment section
  (bug reports/feedback — every tool page gets one, same as articles)
  automatically. Your markdown body is just the content between the
  button row and the top: what the tool does, wiring/setup, safety notes,
  how to get it running. Don't add your own "Launch"/"View on GitHub"
  buttons, comment section, or repeat the tag/status badges inside the
  body.

### `app.html`

The tool's actual web app — not templated by the site at all, served
byte-for-byte as a static file at `/tools/<id>/app/`. It's a separate,
self-contained page (its own `<html>`, its own `<style>`) — but **it
must still look like it belongs to the site**: same color tokens, same
fonts, same component shapes (2px corners, the same card/button/badge
treatment). A visitor clicking "Launch" should never feel like they left
for a different, unrelated product. Concretely:

- Same single dark theme, no light/dark toggle — copy the color values
  below into the app's own `:root` (give your existing variable *names*
  these values; don't rename variables your script already references).
- Same fonts, loaded via the same Google Fonts request as the rest of
  the site (the one exception to "no external dependencies" — this one
  external stylesheet request is expected and fine):

  ```html
  <link rel="preconnect" href="https://fonts.googleapis.com" />
  <link rel="preconnect" href="https://fonts.gstatic.com" crossorigin />
  <link
    rel="stylesheet"
    href="https://fonts.googleapis.com/css2?family=Big+Shoulders+Display:wght@700;800;900&family=Archivo:wght@400;500;600;700&family=IBM+Plex+Mono:wght@400;500;600&display=swap"
  />
  ```

  Body copy → `"Archivo", -apple-system, BlinkMacSystemFont, "Segoe UI", Roboto, Helvetica, Arial, sans-serif`.
  Headings → `"Big Shoulders Display", "Archivo", sans-serif`, bold, uppercase.
  Labels/mono/code/readouts → `"IBM Plex Mono", "SFMono-Regular", Consolas, "Liberation Mono", Menlo, monospace`.

- Same color values (site tokens on the left, in case your app's own
  variable names differ):

  ```css
  --bg: #102C44;            /* page background */
  --bg-raised: #17395A;     /* card backgrounds */
  --bg-raised-alt: #1D4266; /* nested surfaces: inputs, tabs, chart plot areas */
  --text: #F3F8FC;
  --text-dim: #A9C7DE;
  --text-faint: #6E93B1;
  --border: #2C5678;
  --border-strong: #3F7096;
  --accent: #F2A93C;        /* primary buttons, focus rings, the "good/naive-baseline" data series */
  --danger: #EF6F6C;        /* destructive/abort actions, error states */
  --series-1: #8FD3F4;      /* a second data-series color, distinct from --accent */
  --shadow: 0 0 0 1px rgba(230,242,250,0.06), 0 14px 32px -16px rgba(4,12,20,0.65);
  ```

  If the app needs a third or fourth distinct data-series color beyond
  `--accent`/`--series-1`, pick something that reads clearly against the
  dark surfaces above (a teal/green around `#4FD8B0` has worked well) —
  it doesn't need to be a token already in this list.
- 2px border-radius everywhere (cards, buttons, inputs, badges/pills —
  not a fully-rounded pill shape), `--shadow` on cards and buttons,
  matching the rest of the site's "sharp, technical" look rather than a
  soft rounded dashboard aesthetic.
- Reskin only — don't restructure the app's own layout, class names, or
  script logic to do this. If colors are already threaded through the
  app as `var(--whatever-name)` (in CSS *and* in any inline
  `style="..."` attributes or chart-drawing script), you only need to
  change the values each name resolves to, exactly like `.chart-figure`
  on the main site remaps `--series-1`/`--text`/etc. to a different
  palette without touching any SVG markup. If colors are hardcoded
  instead, introduce named variables for them first, then set the
  values above.

### ⚠️ The draft default is "published," not "draft"

**`draft` defaults to `false` (published) if you omit it.** There is no
safety net — a file with no `draft` field goes live the moment its
source repo is registered and the site rebuilds. Always write
`draft: true` explicitly while a piece is still being drafted, and only
remove it (or flip it to `false`) once you have explicit go-ahead to
publish.

---

## 3. Layout: two intentional widths, not a bug

The site uses two content-column widths, both deliberate:

| Token | Width | Used for |
|---|---|---|
| `.wrap` | 60rem | Home, project/tool listing pages, **tool landing pages** (`tool.md`) — anything with a "page" structure: headings, short sections, cards, button rows |
| `.prose-frame` | 43rem (nested inside `.wrap`) | Continuous long-form reading content — `article.md`, `data.md` |

**Rule of thumb**: if what you're writing reads like a landing page
(short sections, a diagram, a button row at the end) → wide, don't wrap
it. If it reads like an essay (paragraph after paragraph, the reader is
expected to read start to finish) → narrow, prose-optimized for line
length.

This is decided by which page template renders the content, not by
anything you write in the markdown file itself — `tool.md` always renders
wide, `article.md`/`data.md` always render narrow. Nothing to configure
per-file.

---

## 4. Visual language

### Theme

Single dark "blueprint" theme — deliberately no light/dark toggle, no
`prefers-color-scheme` split. Don't add one; a blueprint is definitionally
dark blue with pale linework.

### Color tokens

Reference these by CSS custom property name in any hand-written HTML/SVG
— never hardcode a hex value in content. The site may re-theme these
tokens later; content that references them by name stays correct, content
with hardcoded hex values won't.

| Token | Meaning |
|---|---|
| `--bg`, `--bg-deep`, `--bg-raised`, `--bg-raised-alt` | Page background, darker recess, raised card surface, a further-raised variant |
| `--text`, `--text-dim`, `--text-faint` | Primary / secondary / tertiary text |
| `--border`, `--border-strong` | Hairline / emphasized borders |
| `--accent`, `--accent-ink`, `--accent-soft` | Brand accent (orange) / text color for on-accent surfaces / a soft accent wash |
| `--danger` | Error/warning state |
| `--series-1`, `--series-2` | The two-way categorical palette for any chart comparing exactly two things (e.g. "naive" vs "calibrated") |
| `--model-*` (`-linear2`, `-table10` … `-table50`) | A five-way gradient for charts comparing many variants at once — deliberately close together in hue, not a rainbow, when the variants are all close in value (a rainbow would visually overstate differences that aren't really there) |
| `--font-body`, `--font-display`, `--font-mono` | Body copy / heading (condensed display) / monospace (labels, code, timestamps, tags) |

### Typography

- Headings (`h1`–`h4`) use `--font-display`, bold, tight line-height.
  Page-level headings (article/tool page `h1`, section `h2`s) render
  uppercase automatically via the surrounding template — you don't add
  `text-transform` yourself.
- Body copy uses `--font-body`. Secondary/muted text (captions, card
  descriptions) uses `--text-dim` or `--text-faint`, not full-opacity
  `--text`.
- `--font-mono` is for anything label-like: tags, status badges,
  timestamps, inline `code`, axis labels/legends inside charts.
- Don't hand-set `font-size`/`font-family` in your markdown body — write
  semantic HTML (`h2`, `h3`, `p`, `ul`, `table`, `img`) and the page's
  existing styles handle the look. The one place you do set styles by
  hand is inside a hand-built chart SVG (see §5).

### Components the templates already provide (don't hand-author these)

- **Tag row + status badge** (`.tag-row`, `.tag`, `.status-badge`) — driven
  by `tags`/`status` frontmatter on tool and project pages.
- **Button row** (`.button-row`, `.btn`, `.btn.primary`) — the tool page's
  Launch/GitHub buttons are supplied automatically from `repo` frontmatter
  and the tool's slug.
- **Card grid** (`.project-grid`, `.project-card`, `.project-links`) — the
  Tools/Projects listing pages build these from each entry's frontmatter.

You will never write these class names by hand in `article.md`/`tool.md`
— they belong to the page template, not the content.

---

## 5. Charts & diagrams (inline SVG)

Data charts and technical diagrams are hand-authored inline SVG, wrapped
in a `.chart-figure` card:

```html
<div class="chart-figure">
<p class="chart-title">Short label for what this chart shows</p>
<svg viewBox="0 0 680 260" role="img" aria-label="A full plain-language description of what the chart shows and its key takeaway — this is the only description a screen reader gets.">
  <!-- gridlines: stroke="var(--border)" -->
  <!-- axis labels: font-family="var(--font-mono)" fill="var(--text-faint)" -->
  <!-- data: stroke/fill="var(--series-1)" or "var(--series-2)" (two-way) or "var(--model-*)" (many-way) -->
</svg>
<div class="chart-legend">
  <span><span class="swatch" style="background: var(--series-1);"></span>Label for series 1</span>
  <span><span class="swatch" style="background: var(--series-2);"></span>Label for series 2</span>
</div>
<p class="chart-caption">One or two sentences of caption/context below the chart.</p>
</div>
```

Rules:

- **Always reference colors via `var(--token)`, never a literal hex.**
  `.chart-figure` locally redefines every one of these token *names* to a
  light palette (white background, dark ink, MATLAB-style axis colors) —
  charts render light-on-white for data-reading clarity even though the
  rest of the page is dark. An SVG that hardcodes a hex color instead of
  `var(--text)`/`var(--series-1)`/etc. won't pick up that remap and will
  look wrong (often invisible — e.g. pale text on the chart's white
  background).
- `viewBox` only, no explicit `width`/`height` attributes on the `<svg>` —
  it needs to scale to its container.
- `role="img"` and a full descriptive `aria-label` on every `<svg>` are
  required — screen readers cannot parse SVG internals, so the
  `aria-label` is the chart's entire accessible content. Describe the
  actual finding/shape, not just "a chart of X".
- `.chart-legend`/`.swatch` for a manual color-key when the chart itself
  doesn't label series inline.
- `.chart-title` above the SVG, `.chart-caption` below it — both plain
  `<p>` tags, not part of the SVG.
- Many small similar charts (e.g. one subplot per unit/case)? Use
  `.subplot-grid` > `.subplot` (each holding its own small `<svg>` +
  `.subplot-caption`) inside one `.chart-figure`, instead of one full
  `.chart-figure` per item — reads as one figure with several panels
  instead of a wall of near-identical cards.

A **plain content image** (a photo, a wiring diagram photo/rendering) is
not a chart — just use normal markdown `![alt text](path)`. It's already
styled (bordered, centered, shadowed) with no wrapper needed. Reserve
`.chart-figure` for actual data visualizations/technical diagrams.

---

## 6. Images

- Store under `website/images/` in this repo.
- Reference in markdown as `/images/<this-repo's-content-id>/<filename>`
  — the `id` is whatever this repo's source entry is registered under in
  the website's `content.config.ts` (ask if you don't know it, or check
  that repo's `articleSources`/`toolPageSources` entry). The website's
  build fetches the file from `website/images/<filename>` here and writes
  it to that URL — the path in your markdown is the *destination* URL,
  not a path within this repo.
- No automatic image optimization exists yet — keep source images
  reasonably sized before committing.

---

## 7. The Astro markdown gotcha: no blank line inside a raw HTML block

The site's markdown renderer drops back into Markdown mode the instant it
sees a blank line inside a raw HTML block (a `<div>`, `<svg>`, `<figure>`,
etc.) and renders everything after that point as an escaped code block
instead of real markup — silently, with no build error. Keep every raw
HTML/SVG block (charts, custom wrappers) as one continuous block of
non-blank lines from its opening tag to its closing tag. This is the most
common way hand-written charts break; if a chart renders as visible
`<div>`/`<svg>` source text instead of an actual chart, check for a blank
line inside it first.

A plain GFM markdown table doesn't have this problem and needs no special
handling — wide tables already scroll within their own container
automatically.

---

## 8. Before publishing: quick checklist

- [ ] `draft: true` explicitly set while still drafting (see §2's warning
      — the schema default is *published*)
- [ ] Every hand-written SVG uses `var(--token)` colors, not hex
- [ ] Every `<svg>` has `role="img"` and a real descriptive `aria-label`
- [ ] No blank line inside any raw HTML/SVG block
- [ ] Images live in `website/images/`, referenced by their website URL
      (`/images/<id>/<filename>`), not a repo-relative path
- [ ] Any kept editable source for an image (Fritzing/KiCad/etc.) lives in
      `website/sources/`, named to match that image's basename
- [ ] `tool.md` doesn't re-implement the tag row, status badge,
      Launch/GitHub buttons, or comment section — those come from the
      template automatically
- [ ] `app.html` uses the site's color tokens/fonts/2px-radius look
      (§2's `app.html` section) — it shouldn't look like a different
      product once you click Launch
- [ ] This repo's `website/STYLE_GUIDE.md` matches the canonical copy in
      the `vishwamaggarwal.com` repo (diff them if unsure)

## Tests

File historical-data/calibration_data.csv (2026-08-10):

pulse_us | angle_deg | valid
1483 | 89.033 | 1
1482 | 88.945 | 1
1481 | 88.945 | 1
1480 | 89.033 | 1
1479 | 88.857 | 1
1478 | 88.682 | 1
1477 | 88.506 | 1
1476 | 88.506 | 1
1475 | 88.506 | 1
1474 | 88.506 | 1
1473 | 88.506 | 1
1472 | 88.506 | 1
1471 | 88.242 | 1
1470 | 88.066 | 1
1469 | 87.891 | 1
1468 | 87.891 | 1
1467 | 87.803 | 1
1466 | 87.803 | 1
1465 | 87.803 | 1
1464 | 87.803 | 1
1463 | 87.539 | 1
1462 | 87.275 | 1
1461 | 87.187 | 1
1460 | 87.187 | 1
1459 | 87.012 | 1
1458 | 86.836 | 1
1457 | 86.836 | 1
1456 | 86.836 | 1
1455 | 86.660 | 1
1454 | 86.484 | 1
1453 | 86.309 | 1
1452 | 86.309 | 1
1451 | 86.221 | 1
1450 | 86.309 | 1
1449 | 86.309 | 1
1448 | 86.309 | 1
1447 | 86.221 | 1
1446 | 85.957 | 1
1445 | 85.869 | 1
1444 | 85.781 | 1
1443 | 85.781 | 1
1442 | 85.781 | 1
1441 | 85.781 | 1
1440 | 85.781 | 1
1439 | 85.781 | 1
1438 | 85.518 | 1
1437 | 85.254 | 1
1436 | 85.078 | 1
1435 | 85.078 | 1
1434 | 84.990 | 1
1433 | 84.902 | 1
1432 | 84.902 | 1
1431 | 84.814 | 1
1430 | 84.727 | 1
1429 | 84.463 | 1
1428 | 84.375 | 1
1427 | 84.375 | 1
1426 | 84.375 | 1
1425 | 84.111 | 1
1424 | 84.023 | 1
1423 | 84.023 | 1
1422 | 83.848 | 1
1421 | 83.848 | 1
1420 | 83.936 | 1
1419 | 83.760 | 1
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

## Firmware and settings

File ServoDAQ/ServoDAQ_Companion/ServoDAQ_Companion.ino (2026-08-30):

/*
  ServoDAQ_Companion

  Boots into a known state, then takes a raw pulse width and reports back
  the settled shaft position. No zero reference (position is relative to
  wherever the shaft happened to be at boot), no model -- that's the
  host's job. Unit conversion (raw AS5600 counts -> centidegrees) *is*
  done here now, and so is multi-turn unwrapping -- see below.

  Everything runs on one fixed-rate loop (200Hz): reading serial, reading
  the encoder, differentiating, writing the servo, and deciding "settled"
  all happen on the same tick, nothing in a nested blocking sub-loop. The
  fixed period is what makes a raw delta between ticks mean velocity,
  regardless of anything else going on -- and why no separate filtering
  step is needed; the reported value is just the average of the raw
  samples across the stable dwell window.

  Multi-turn position tracking: the AS5600 itself only ever reports a
  raw 12-bit angle, 0-4095, that wraps every revolution -- it has no
  concept of "which lap." updatePositionTracking() turns that into a
  signed, monotonic, unwrapped position by watching for a same-direction
  jump bigger than half a revolution between two *consecutive* samples
  and crediting it to a whole-turn count instead of a real move. That
  unwrap is Universal-Encoder-Interface's (AS5600EncoderDriver in
  continuous mode); this file used to implement it locally and no longer
  does. The tracked position is carried in radians, since that is the
  only form UEI exposes an unwrapped reading in -- converted to
  centidegrees at the same single boundary as before, so nothing on the
  wire changed. That's safe here because nothing this
  servo does can complete a full revolution between consecutive samples
  at this sample rate (tick() samples every 5ms; CAP, the fastest path,
  samples every I2C transaction, well under that) -- a real single-step
  move of more than 2048 counts between reads 5ms apart is not physically
  possible for a hobby servo, so any jump that big is unambiguously a
  wrap, never mistaken for real motion. This is the ONLY place in the
  firmware that reads the encoder, and it runs first, unconditionally,
  before any mode-specific logic (settling, streaming, anything) -- so
  every consumer (tick's settle detector, CAP's capture loop) sees the
  same always-continuous position, and nothing downstream -- not this
  firmware, not the host script, not a plot -- ever needs to unwrap a
  wraparound after the fact.

  Wire values are centidegrees (degrees x100), not raw counts. The
  AS5600's native resolution is 360/4096 = 0.087890625 deg/count (~8.79
  centidegrees/count); centidegrees give ~0.01 deg of resolution, about
  8.8x finer than the sensor's own quantization step, so nothing is lost
  by converting, and the wire format stays a plain signed integer with
  no float parsing needed on the host.

  Protocol (115200 baud, one command per line, \n-terminated ASCII).

    PING           -> OK PONG

    US <pulseUs>   -> OK <pulseUs> <centideg>
                     | ERR NOT_SETTLED <pulseUs> <centideg>
                     | ERR OUT_OF_RANGE <floor>..<ceil>
                     | ERR USAGE
                     | ERR BUSY
      One direct Servo.writeMicroseconds(pulseUs) -- no ramping. Starts
      settling and replies once the tick loop confirms it (or times out).
      A second US sent before that reply arrives gets ERR BUSY -- one in
      flight at a time, never queued or overlapped.
      centideg (OK case) is the settled shaft position in centidegrees,
      signed, relative to wherever the shaft was at boot (0) -- averaged
      over the stable dwell window. Monotonic across turns: never wraps.
      NOT_SETTLED means SETTLE_TIMEOUT_MS elapsed without
      SETTLE_DWELL_TICKS of consecutive <=SETTLE_DELTA_RAD deltas ever
      being observed -- centideg here is just the single last raw
      reading, not a genuinely stable value, and the shaft may still be
      moving when this reply arrives. Previously reported as a plain OK
      indistinguishable from a real settle; see the file's own history
      for why that was a real bug for a servo with nothing to settle
      against.

    CAP <pulseUs> <delayMs>
                   -> CAPSTART <pulseUs>
                      (streamed) CP <tMs> <centideg>  -- one per sample
                      CAPEND <count>
                     | ERR OUT_OF_RANGE <floor>..<ceil>
                     | ERR DELAY_OUT_OF_RANGE 0..1000
                     | ERR BUSY
      Diagnostic only -- not part of normal operation, a deliberate
      exception to "everything happens on the tick" the same way
      blocking was an accepted exception for CALIBRATE in the old
      firmware. tick()'s fixed period matters for making a delta mean
      velocity; CAP doesn't make any on-device decision at all, it just
      timestamps samples for the host to look at, so sampling as fast as
      I2C allows (delayMs=0) -- or slower, if delayMs>0, to trade
      resolution for a longer capture window against a fixed sample
      buffer -- is fine and is the point. One direct write, no settle
      wait; streams the whole burst only after it's done (printing
      mid-loop would slow the sampling rate and skew the timing being
      captured). Each sample still goes through the same single tracked
      read as tick(), so a CAP burst is monotonic too, same as US.

  Lines starting with "#" are informational only -- not part of the
  command/response protocol, safe to log-and-ignore.
*/

#include <Arduino.h>
#include <Wire.h>
#include <Servo.h>
// Universal-Encoder-Interface -- owns the multi-turn unwrap this file used
// to hand-roll. Still built on RobTillaart's AS5600 underneath (UEI wraps
// it), and pulls in Universal-Device-Interface, UEI's own dependency.
#include <AS5600EncoderDriver.h>
#include <string.h>

const int SERVO_PIN = A3;

// Hard safety fence only -- guards against an absurd pulse width
// regardless of what the host asks for.
//
// ABS_CEIL_US must also stay inside what Servo::attach() can actually
// encode: internally it stores (MAX_PULSE_WIDTH - max)/4 in a signed
// int8_t (Servo.h: MAX_PULSE_WIDTH 2400), so any ceiling above
// 2400 + 4*127 = 2908 (2912 rounds cleanly to the same 4us step Servo.cpp
// itself uses) silently overflows and wraps. The old value here, 3100,
// computed (2400-3100)/4 = -175, which doesn't fit in int8_t and wraps to
// 81, giving an ACTUAL enforced ceiling of 2400-81*4 = 2076us -- every
// commanded pulse above ~2076us was silently rewritten to 2076us the
// whole time, indistinguishable from the servo genuinely stalling right
// there. Found by comparing this project's own find_range() output
// against Servo_Test.ino (a sibling sketch on the same hardware that
// deliberately caps at 2912us for exactly this reason) and tracing the
// ~2076us "edge" both ServoDAQ and ServoCalibrator_Companion kept
// reporting back to this overflow -- not a real mechanical limit. See
// ServoCalibrator_Companion.ino's own ABS_CEIL_US comment and the
// 2026-08-25 CLAUDE.md entry for the full finding. This affects every
// max_pulse_us this project has ever recorded via find_range() on a
// servo whose true range exceeds ~2076us.
const int ABS_FLOOR_US = 80;
const int ABS_CEIL_US  = 2912;
const int CENTER_US    = 1500;

// Tick rate for the whole program -- long enough to comfortably contain
// one AS5600 read at 400kHz I2C, fast enough that a delta between ticks
// is a fine-grained velocity signal.
const unsigned long LOOP_PERIOD_MS = 5;   // 200Hz

// Settling thresholds, all keyed off that fixed tick period.
// Max |pos[n]-pos[n-1]| between ticks to count as stopped. Still "2 AS5600
// counts" -- the sensor's own quantization is what this has always meant --
// just expressed in radians now that the tracked position is radians (see
// updatePositionTracking()), written as the conversion rather than a
// pre-rounded decimal so it stays correct by construction.
const int   SETTLE_DELTA_COUNTS = 2;
const float SETTLE_DELTA_RAD    = SETTLE_DELTA_COUNTS * (2.0f * 3.14159265358979f / 4096.0f);
const int           SETTLE_DWELL_TICKS  = 40;   // 200ms sustained
const unsigned long SETTLE_TIMEOUT_MS   = 3000; // safety net -- slowest real move measured so far was under 1s

Servo servo;

// continuous = true: readPhysicalAngleRad() accumulates across revolutions
// rather than resetting at the AS5600's 4096-count wrap.
AS5600EncoderDriver encoder(Wire, /*continuous=*/true);

// ------------------------------------------------------------------
// Position tracking -- now owned by Universal-Encoder-Interface's
// AS5600EncoderDriver rather than hand-rolled here. This file used to keep
// its own signed lap counter and rebuild a continuous position as
// turnCount*4096 + raw; UEI's unwrapRawCounts() (EncoderMath.h) is that
// same algorithm with the same half-revolution-between-samples assumption,
// maintained and tested in one place, so the local copy was deleted rather
// than kept in parallel. The assumption is as safe here as it ever was --
// this file samples at 200Hz, and CAP faster still.
//
// The carried unit is RADIANS now, not counts: UEI exposes its unwrapped
// reading only as a float angle (readRawCounts() is deliberately always the
// bounded 0..4095 register and cannot carry lap information). Conversion to
// centidegrees still happens at exactly the same boundary as before, so the
// wire protocol is byte-for-byte unchanged.
//
// readPhysicalAngleRad(), not readAngleRad(): no software zero offset is
// applied, so the boot reading is the shaft's absolute angle -- exactly
// what this firmware reported before (it seeded totalCounts from the raw
// register, not from zero). The host works in relative terms and re-zeros
// on every connection anyway.
// ------------------------------------------------------------------
float totalRad = 0.0f;   // continuous, unwrapped position in radians

// The only place anywhere in this program that reads the encoder.
float updatePositionTracking() {
  totalRad = encoder.readPhysicalAngleRad();
  return totalRad;
}

// radians -> centidegrees (degrees x100). lroundf() rounds to nearest and
// is symmetric about zero, so a negative position (shaft below its boot
// reference) rounds the same way a positive one does -- the same property
// the previous integer implementation went out of its way to preserve, now
// for free. 18000/PI is the exact analogue of that version's 36000/4096
// counts-based ratio.
const float CENTIDEG_PER_RAD = 5729.577951308232f;

long radToCentideg(float rad) {
  return lroundf(rad * CENTIDEG_PER_RAD);
}

// ------------------------------------------------------------------
// Command line assembly. Non-blocking: only ever consumes what's
// currently sitting in the serial buffer.
// ------------------------------------------------------------------
const int LINE_BUF_LEN = 32;
char lineBuf[LINE_BUF_LEN];
int lineLen = 0;

const int MAX_TOKENS = 4;
char* tok[MAX_TOKENS];
int tokenize(char* line) {
  int n = 0;
  char* p = line;
  while (*p && n < MAX_TOKENS) {
    while (*p == ' ') p++;      // skip leading/repeated spaces
    if (!*p) break;
    tok[n++] = p;
    while (*p && *p != ' ') p++;
    if (*p) { *p = '\0'; p++; } // terminate this token, advance past it
  }
  return n;
}

// ------------------------------------------------------------------
// Runtime state -- persists across ticks, not local to a nested loop.
// mode tracks whether a US command is in flight; tick() advances it one
// step per call, whether that call lands during an idle period or one
// mid-command.
// ------------------------------------------------------------------
enum Mode { MODE_IDLE, MODE_SETTLING };
Mode mode = MODE_IDLE;

int targetPulseUs = CENTER_US;   // echoed back in the reply
float settleSum = 0.0f;          // sum of position samples (radians) across the stable dwell window
int settleStableCount = 0;
unsigned long settleStartMs = 0;
unsigned long nextTickMs = 0;
float prevTickTotal = 0.0f;      // position as of the previous tick, for settle-delta comparison

// Reports the settled value, or -- if SETTLE_TIMEOUT_MS elapsed without
// ever actually settling -- an ERR instead of a fake OK. lastTotal in
// the timeout case is just whatever the single last raw reading was,
// not a genuinely stable value, and the shaft may still be moving right
// now; reporting it as an error (not success) is the whole fix -- a
// caller that only ever checked reply[0]=="OK" now correctly sees a
// failure instead of silently treating an unsettled reading as real
// data (see this command's protocol comment for the full reasoning).
void reportSettled(float lastTotal, bool converged) {
  if (!converged) {
    Serial.print(F("ERR NOT_SETTLED "));
    Serial.print(targetPulseUs);
    Serial.print(' ');
    Serial.println(radToCentideg(lastTotal));
    mode = MODE_IDLE;
    return;
  }
  // Fine to print directly here: AVR's Serial has a 64-byte TX buffer
  // and this reply is ~16 bytes, so it won't block the tick loop.
  Serial.print(F("OK "));
  Serial.print(targetPulseUs);
  Serial.print(' ');
  Serial.println(radToCentideg(settleSum / (float)settleStableCount));
  mode = MODE_IDLE;
}

// US <pulseUs> -- validate, write, arm settling. Non-blocking: the
// actual detection happens tick by tick in tick() below.
void handleUs(int n) {
  if (n != 2) { Serial.println(F("ERR USAGE: US <pulseUs>")); return; }
  int pulseUs = atoi(tok[1]);
  if (pulseUs < ABS_FLOOR_US || pulseUs > ABS_CEIL_US) {
    Serial.print(F("ERR OUT_OF_RANGE ")); Serial.print(ABS_FLOOR_US); Serial.print(F(".."));
    Serial.println(ABS_CEIL_US);
    return;
  }
  servo.writeMicroseconds(pulseUs);
  targetPulseUs = pulseUs;
  float total = updatePositionTracking();   // fresh seed right as the move starts
  settleSum = total;
  settleStableCount = 1;
  settleStartMs = millis();
  mode = MODE_SETTLING;
}

// ------------------------------------------------------------------
// CAP -- raw step-response capture for diagnosing exactly what US's
// settle detector can't see (e.g. a single-sample discontinuity that
// two independently-settled readings just look like a big gap between).
// Deliberately blocking, deliberately not going through tick() -- see
// this command's protocol comment at the top of the file for why that's
// fine here specifically.
// ------------------------------------------------------------------
struct CapSample { uint16_t tMs; float rad; };
// Halved from 200 back when each sample went from a 2-byte raw reading to
// a 4-byte multi-turn total; a float position is the same 4 bytes, so the
// buffer's RAM footprint is unchanged again here (still RAM-bounded, see
// protocol comment above).
const uint16_t CAP_BUFFER_SIZE = 100;
CapSample capBuf[CAP_BUFFER_SIZE];

void handleCap(int n) {
  if (n != 3) { Serial.println(F("ERR USAGE: CAP <pulseUs> <delayMs>")); return; }
  int pulseUs = atoi(tok[1]);
  if (pulseUs < ABS_FLOOR_US || pulseUs > ABS_CEIL_US) {
    Serial.print(F("ERR OUT_OF_RANGE ")); Serial.print(ABS_FLOOR_US); Serial.print(F(".."));
    Serial.println(ABS_CEIL_US);
    return;
  }
  int delayMs = atoi(tok[2]);
  if (delayMs < 0 || delayMs > 1000) { Serial.println(F("ERR DELAY_OUT_OF_RANGE 0..1000")); return; }

  unsigned long startMs = millis();
  servo.writeMicroseconds(pulseUs);   // direct write -- this is the capture event, not a normal settle

  uint16_t count = 0;
  while (count < CAP_BUFFER_SIZE) {
    capBuf[count].tMs = (uint16_t)(millis() - startMs);
    capBuf[count].rad = updatePositionTracking();   // same single tracked read tick() uses
    count++;
    if (delayMs > 0) delay(delayMs);
  }

  // Converted to centidegrees only here, after capture -- keeps the tight
  // sampling loop above free of the conversion, same reasoning as the
  // original "stream only after it's done".
  Serial.print(F("CAPSTART ")); Serial.println(pulseUs);
  for (uint16_t i = 0; i < count; i++) {
    Serial.print(F("CP "));
    Serial.print(capBuf[i].tMs);
    Serial.print(' ');
    Serial.println(radToCentideg(capBuf[i].rad));
  }
  Serial.print(F("CAPEND ")); Serial.println(count);
}

// Dispatch on the first token. US/CAP while already settling get ERR
// BUSY instead of overlapping with the command in flight.
void handleLine(char* line) {
  int n = tokenize(line);
  if (n == 0) return;
  if (strcmp(tok[0], "PING") == 0) {
    Serial.println(F("OK PONG"));
  } else if (strcmp(tok[0], "US") == 0) {
    if (mode == MODE_SETTLING) { Serial.println(F("ERR BUSY")); return; }
    handleUs(n);
  } else if (strcmp(tok[0], "CAP") == 0) {
    if (mode == MODE_SETTLING) { Serial.println(F("ERR BUSY")); return; }
    handleCap(n);
  } else {
    Serial.println(F("ERR UNKNOWN_CMD"));
  }
}

void readSerialNonBlocking() {
  while (Serial.available()) {
    char c = Serial.read();
    if (c == '\n' || c == '\r') {
      if (lineLen > 0) {        // ignore blank lines (e.g. a lone \r before \n)
        lineBuf[lineLen] = '\0';
        handleLine(lineBuf);
        lineLen = 0;
      }
    } else if (lineLen < LINE_BUF_LEN - 1) {
      lineBuf[lineLen++] = c;   // silently drop anything past LINE_BUF_LEN
    }
  }
}

// One tick: track position, then (only if a command is in flight)
// advance settling. Position tracking happens first, unconditionally,
// every single tick -- everything else is downstream of it. Called
// once per LOOP_PERIOD_MS from loop().
void tick() {
  float total = updatePositionTracking();
  float delta = total - prevTickTotal;   // plain subtraction -- total is already continuous, no wrap fixup needed
  prevTickTotal = total;

  if (mode != MODE_SETTLING) return;

  if (fabsf(delta) <= SETTLE_DELTA_RAD) {
    settleSum += total;
    settleStableCount++;
    if (settleStableCount >= SETTLE_DWELL_TICKS) {
      reportSettled(total, true);
      return;
    }
  } else {
    settleSum = total;
    settleStableCount = 1;
  }

  if (millis() - settleStartMs >= SETTLE_TIMEOUT_MS) {
    reportSettled(total, false);
  }
}

void setup() {
  Serial.begin(115200);
  while (!Serial) {}
  delay(300);   // let the USB-serial adapter settle before printing

  Serial.println(F("# ServoDAQ_Companion booting..."));

  Wire.begin();
  Wire.setClock(400000);  // Fast-mode I2C -- keeps one read comfortably inside a tick
  // UEI's begin() brings the chip up and probes it -- a false return is the
  // ERR_NOT_CONNECTED case the old separate isConnected() check covered.
  if (!encoder.begin()) {
    Serial.print(F("# FATAL: "));
    Serial.print(encoder.getErrorString(encoder.getError()));
    Serial.println(F(". Halting."));
    while (true) {}
  }

  // Magnet diagnostics this firmware had no access to before: an I2C ack
  // says nothing about whether a magnet is present and within AGC range,
  // which is the difference between real readings and plausible garbage.
  if (!encoder.isValid()) {
    Serial.print(F("# WARNING: "));
    Serial.println(encoder.getStatusString(encoder.getStatus()));
  }

  servo.attach(SERVO_PIN, ABS_FLOOR_US, ABS_CEIL_US);
  servo.writeMicroseconds(CENTER_US);   // known starting position, not wherever the last session left it
  totalRad = updatePositionTracking();  // seed UEI's unwrap state from the shaft's current angle
  prevTickTotal = totalRad;

  Serial.println(F("# READY"));
}

void loop() {
  readSerialNonBlocking();   // every pass, not just on-tick -- keeps command dispatch latency low

  if ((long)(millis() - nextTickMs) < 0) return;
  nextTickMs += LOOP_PERIOD_MS;

  tick();
}

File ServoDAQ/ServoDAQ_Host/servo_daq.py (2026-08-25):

"""
ServoDAQ host driver.

Talks to ServoDAQ_Companion.ino over serial (115200 baud, one command per
line, \n-terminated ASCII). See ../ServoDAQ_Companion/ServoDAQ_Companion.ino
for the protocol this drives -- PING and US only; range-finding, models,
and everything else lives here, not on the board.

Position values from the board are signed centidegrees (degrees x100),
already unwrapped across turns by the firmware itself -- see the .ino's
own file-level comment for how. Nothing here needs to (or should) do any
wraparound correction on them; a plain subtraction between any two
readings is always the true delta, and a trace plotted straight out of
this module is monotonic by construction.
"""

import argparse
import time

import serial

# Mirrors the same-named constants in ServoDAQ_Companion.ino -- no shared
# config file between the two, so these have to be kept in sync by hand.
CENTER_US    = 1500
ABS_FLOOR_US = 80
# Must match ServoDAQ_Companion.ino's own ABS_CEIL_US exactly -- was 3100,
# which the AVR Servo library's int8_t-encoded attach() bound silently
# overflows and wraps to an actual enforced ceiling of ~2076us (see that
# .ino's own ABS_CEIL_US comment). 2912 is the real representable max;
# kept in sync here by hand per this module's own docstring.
ABS_CEIL_US  = 2912


class NotSettledError(RuntimeError):
    """US reported ERR NOT_SETTLED: SETTLE_TIMEOUT_MS elapsed without the
    shaft ever meeting the settle criterion. centideg here is just
    whatever the last raw reading was, not a real position -- some
    servos (see servo_daq.py's own history) take an unreachable pulse as
    a cue to spin toward it the long way around instead of stalling, so
    this pulse's own reading is never trustworthy. Carries pulse_us and
    centideg (offset-corrected, same as move_to()'s return) purely for
    diagnostics -- callers should not treat it as a real position."""
    def __init__(self, pulse_us, centideg):
        super().__init__(f"US {pulse_us} did not settle within the timeout (last reading {centideg} centideg)")
        self.pulse_us = pulse_us
        self.centideg = centideg


class ServoDAQLink:
    """One serial connection to the board. Opening the port resets it
    (DTR, same as any Arduino serial terminal), so connect() waits for
    the '# READY' boot banner before anything else is sent.
    """

    def __init__(self, port, baud=115200, timeout=3.0):
        self.ser = serial.Serial(port, baud, timeout=timeout)
        # See recover_from_wrap() -- corrects every centideg this link
        # reports from here on, after a NotSettledError episode moved the
        # shaft somewhere the wrap-safe accumulator didn't expect. Zero
        # (a no-op) until that ever actually happens.
        self.centideg_offset = 0

    def wait_ready(self, timeout=6.0):
        deadline = time.time() + timeout
        while time.time() < deadline:
            line = self.ser.readline().decode(errors="replace").strip()
            if line.startswith("# READY"):
                return True
        return False

    def send_command(self, cmd, timeout=5.0):
        """Send one command, return its reply line. '#' lines are boot/log
        noise, not replies -- skipped, never returned."""
        self.ser.write((cmd + "\n").encode())
        deadline = time.time() + timeout
        while time.time() < deadline:
            line = self.ser.readline().decode(errors="replace").strip()
            if not line or line.startswith("#"):
                continue
            return line
        raise TimeoutError(f"no reply to {cmd!r} within {timeout}s")

    def ping(self):
        reply = self.send_command("PING")
        if reply != "OK PONG":
            raise RuntimeError(f"unexpected PING reply: {reply!r}")

    def move_to(self, pulse_us):
        """US <pulseUs> -> (pulseUs, centideg). Blocks until the board
        reports settled. centideg is signed, unwrapped centidegrees --
        see this module's docstring -- plus centideg_offset (see
        recover_from_wrap()), transparently, so every caller downstream
        of a wrap-recovery just sees corrected values with no special
        handling of their own. Timeout here (5s) is deliberately above
        the firmware's own SETTLE_TIMEOUT_MS (3s) -- a client timeout
        shorter than the device's own worst case is exactly the bug that
        caused a real command-desync problem elsewhere in this project's
        history, not repeating that here.

        Raises NotSettledError (not a plain RuntimeError) specifically
        for ERR NOT_SETTLED -- callers that need to treat "never settled"
        as a real, expected outcome (not a wire-protocol failure) can
        catch that distinctly; anything else not starting with OK
        (OUT_OF_RANGE, USAGE, BUSY) is a genuine protocol-level error and
        still raises plain RuntimeError."""
        reply = self.send_command(f"US {pulse_us}", timeout=5.0)
        parts = reply.split()
        if parts[0] == "ERR" and len(parts) > 1 and parts[1] == "NOT_SETTLED":
            raise NotSettledError(int(parts[2]), int(parts[3]) + self.centideg_offset)
        if parts[0] != "OK":
            raise RuntimeError(f"US {pulse_us} rejected: {reply}")
        return int(parts[1]), int(parts[2]) + self.centideg_offset

    def recover_from_wrap(self, candidates):
        """Call right after a NotSettledError to recenter onto a pulse
        whose true position is already known, and correct
        centideg_offset so every reading for the rest of this session is
        back in a physically consistent frame.

        `candidates` is an ordered list of (pulse_us, known_centideg)
        fallback points, tried nearest/most-specific first. One point
        isn't enough: real hardware showed the recovery move itself can
        also hit NotSettledError -- the danger zone's edge isn't
        perfectly repeatable run to run (observed anywhere from 250 to
        270us across trials), so "the last good pulse from this walk"
        isn't always reliably safe to return to on the very next
        command. Each caller should pass at least one further-back point
        it's confident is genuinely clear of the edge (e.g. this scan's
        own starting pulse) as a fallback beyond the immediate one.
        Raises the last NotSettledError if every candidate fails --
        at that point something more serious is going on than this
        function's job to paper over.
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

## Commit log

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2026-08-10 Merge Servo Calibrator + Trajectory Demo into one characterization tool
    Per explicit direction: purely for characterization (no installation
    wizard, no generated driver constructor -- that's a UMI-application
    concern now), always physical-frame [0, maxAngleDeg] (no direction/
    logical-zero setup), one CALIBRATE button that runs the whole
    stall-scan + sweep automatically, then the existing trajectory-demo
    interface unchanged, plus table import/export.
    Firmware (ServoCalibrator_Companion.ino, replacing both predecessors):
    - CALIBRATE: on-device stall-scan + bidirectional sweep (adapted from
    UMI's own examples/RCServoAutoCalibration), builds a 20-point
    direction-averaged table, streams prog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
    [ServoCalibrator_Companion.ino]
2026-08-10 Fix CALIBRATE against a fast/wide-range digital servo (3 real bugs)
    Widened ABS_FLOOR_US/ABS_CEIL_US (200/2900 -> 80/3100) -- this servo's
    real range sits outside what was tuned for the analog servo this
    firmware was developed against.
    Found and fixed, in order, via actual hardware diagnostics (added
    trace output, read the data, changed the theory) rather than guessed:
    1. sweepUp()'s initial big jump was preceded by a blind delay(400)
    before any angle tracking started -- for a fast servo capable of
    covering most of its range inside that window, the first tracked
    sample was already wrong.
    2. Fixing #1 alone didn't help -- 18/20 table points stuck at 0. This
    servo can sit with ge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
    [ServoCalibrator_Companion.ino]
2026-08-10 Fix command-desync bug: widen IMPORT timeout, add a command busy-lock
    Real bug hit live: IMPORT's 15s client-side timeout was shorter than
    its own worst-case re-anchor time (rampTo() can legitimately take 20+
    seconds), so a still-in-progress IMPORT got wrongly treated as failed.
    The device kept working regardless -- a client timeout doesn't stop
    it -- and the UI let more commands through immediately after, queueing
    them behind the still-in-flight first IMPORT. Once its late reply
    arrived, it got consumed by whichever sendCommand() was waiting at
    that moment, misdelivering every reply after it by one slot (GO showed
    an IMPORT error, etc).
    Fixed the timeout (15s -> 90s) but also, more importa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
2026-08-10 Fix boot-time serial garbage getting misdelivered as a command reply
    A garbled byte or two from the USB-serial adapter resyncing right as
    opening the port resets the board (via DTR) can prefix what should be
    a clean boot-log line -- SerialLink._onLine() only recognizes ignorable
    log lines by a literal leading '#', so a garbled prefix made one fall
    through to the generic reply path and get queued as if it were an
    answer to some future command. The next real command (GETTABLE, sent
    automatically on connect) silently consumed it instead of the device's
    real reply, which then queued up and got consumed by the *next* real
    command (IMPORT) instead -- misdelivering every reply after the boot
    garbag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
2026-08-11 README: fix staleness from today's fixes (ABS bounds, ramp timing)
    - Safety-ceiling numbers were still the pre-widen defaults (200-2900 ->
    actual 80-3100).
    - Import's re-anchor description still said 'a couple of seconds' --
    now correctly describes the ramped moves (up to 20+s) and the 90s
    timeout that matches.
    - Added a note in Quick start explaining CALIBRATE/IMPORT's
    deliberately slow, incremental movement, so it doesn't read as a
    stall to someone trying this for the first time.
2026-08-17 Add ServoDAQ tool; give it on-device multi-turn position tracking
    ServoDAQ is a separate bench-characterization companion (firmware +
    Python host driver), kept out of ServoCalibrator per standing practice.
    ServoDAQ_Companion.ino: replaced raw 0-4095 AS5600 counts on the wire
    with on-device multi-turn tracking. updatePositionTracking() is the
    only place the encoder is read, runs first every tick before any
    mode-specific logic, and folds each new sample against the last one --
    a same-direction jump over half a revolution between two consecutive
    samples (200Hz tick, CAP even faster) is treated as a wrap and credited
    to a signed lap counter rather than mistaken for real motion. Position
    is repo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
    [ServoDAQ_Companion.ino, servo_daq.py, study_range.py]
2026-08-17 ServoDAQ: guard find_range() against a real stall-recovery backoff
    Live hardware investigation (naive vs smart low-side edge disagreeing
    by ~300 degrees) traced through several ruled-out theories -- unwrap
    algorithm bug, stray AS5600 sample, real horn rotation (visually
    disproven), magnet/sensor mounting (survived a full reseat unchanged),
    shared power, shared ground -- down to the actual cause: this digital
    servo runs its own internal stall/overcurrent protection. Driven hard
    enough past its real mechanical limit for long enough, it deliberately
    backs itself off, smoothly, over roughly 1.6-1.8s -- real motion,
    confirmed by directly watching it happen and by a servo-disconnected
    control (zer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
    [plot_naive_vs_smart.py, servo_daq.py]
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2026-08-17 ServoDAQ: fine calibration sweep + full docs writeup
    study_range.py: once find_range() has reliably located the real
    min/max, run a fine calibration sweep (plain sweep(), no stall
    detection needed) at 5us steps across the full range in both
    directions (min->max, then max->min) -- separates direction-dependent
    backlash from angle-dependent nonlinearity, same reasoning as
    historical-data/hysteresis_data.csv. Also now saves find_range()'s own
    coarse/fine sub-traces, so one connection/session produces every trace
    needed to plot naive vs. coarse vs. fine vs. the fine sweep together on
    one consistent centideg reference.
    Add ServoDAQ/README.md: full writeup of the stall-recovery-backoff
    investigat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
    [study_range.py]
2026-08-17 ServoDAQ: N-point lookup-table accuracy test, folded into study_range.py
    Implements the "Planned next step" from CLAUDE.md: validates 2-point
    linear vs. 10/20/30/40/50-point lookup tables against real hardware,
    not just curve-fit residuals. Direction-averages the fine sweep into
    one ground-truth pulse->angle curve, builds each model from it (binary
    search + linear interpolation, same algorithm the real embedded tools
    use), then repeatedly: picks one random target angle, computes every
    model's predicted pulse for it (order randomized per round so no model
    is systematically first/last and biased by leftover backlash), commands
    each, and measures the real resulting angle. This is the actual
    end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
    [study_range.py]
2026-08-17 ServoDAQ: document N-point accuracy test results (first real run)
    Overnight run completed cleanly: 3 hours, 1411 rounds, 8466 real
    hardware trials (stamp 20260817-005841). Writes up the results in both
    CLAUDE.md and ServoDAQ/README.md:
    - Any lookup table beats the naive 2-point linear assumption by a real,
    consistent margin (mean error ~25-29% lower, median ~33-35% lower,
    RMS ~20-27% lower, across every table size tested).
    - Diminishing returns past ~20-30 points -- table20/30/40/50 cluster
    tightly together, consistent with this project's existing 20-point
    table convention not being undersized for a servo like this one.
    - One honestly-reported counterintuitive result: table10's max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
2026-08-17 ServoDAQ: degrees in accuracy CSV, motor type/unit labeling
    accuracy_trials CSV now writes target/actual angle and error in plain
    degrees (target_angle_deg/actual_angle_deg/error_deg) instead of
    centidegrees -- this file has no downstream reader in the codebase
    (only ad hoc analysis), so there's no interoperability reason to match
    the rest of the project's centideg convention, and degrees is much
    easier to eyeball in a raw row. Internal math (table interpolation,
    target sampling, error) still stays in centidegrees throughout, same as
    everywhere else in this project.
    Every output filename now carries motor_type/unit (plain integers,
    type<N>_unit<M>_<timestamp>_*.csv) so the planned 8-servo s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
    [study_range.py]
2026-08-17 ServoDAQ: correct CLAUDE.md/README accuracy numbers, document the fix
    The stale numbers from the flawed clustered-round accuracy test were
    still in both docs (mean ~25-29% reduction vs. naive, table10's max
    beating linear2). Replaced with the corrected run's real numbers
    (mean ~63-67% reduction; linear2 actually has the worst max of all six
    models) and a full writeup of the flaw itself -- how it was diagnosed
    (position-in-round vs. error, ruling out jump distance and directional
    bias) and the fix (fully decoupled random angle + random model per
    trial). Also documents the degrees-CSV and motor-type/unit-labeling
    follow-ups from the same day.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
2026-08-18 ServoDAQ: degrees in every sweep/calibration CSV; add wrap-up skill
    Extends the earlier accuracy-CSV-only degrees fix to every CSV
    study_range.py and plot_naive_vs_smart.py write (naive/fine/smart/
    summary, plus the one-off investigation scripts' capture CSVs) --
    angle_deg replaces raw centideg everywhere. plot_full_range.py, the
    only script that re-reads these from disk, updated to match. Internal
    math stays centidegrees throughout; only CSV output changes, and only
    on the Python side -- firmware/wire protocol untouched.
    Triggered by a laptop crash that killed an in-progress type1_unit1 run
    partway through its accuracy phase; that stamp's data (well-formed but
    incomplete) was discarded rat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
    [plot_full_range.py, plot_naive_vs_smart.py, study_range.py]
2026-08-18 ServoDAQ: document type1_unit1 accuracy results (first unit of 8-servo study)
    Restarted after the crash/CSV-degrees fix from the previous session:
    full study_range.py run against type1_unit1 (Miuzei 25kg Servo),
    3h accuracy phase, 6482 independent trials, stamp 20260817-170727.
    Range 345-2080us, -38.76 to 194.06deg (~232.8deg stroke).
    Same qualitative picture as the earlier reference run: linear2's mean
    error ~3x any table model's, returns diminish sharply past ~10-20
    points. Reads as independent confirmation on different hardware, not
    a new finding. 7 units remain toward the planned 8-unit study.
2026-08-19 ServoDAQ: fix silent settle-timeout ack, handle servos that spin past their edge
    type3_unit1 (MG90D) spun continuously instead of stalling during phase 1.
    Two real fixes:
    1. ServoDAQ_Companion.ino's reportSettled() sent an identical OK reply
    whether the shaft genuinely converged or the 3s settle timeout just
    expired -- the host had no way to tell a real settle from a
    possibly-still-moving reading. Timeout case now sends
    ERR NOT_SETTLED <pulseUs> <centideg> instead.
    2. With that visible, the real cause turned out not to be a sensor
    glitch (first guess, retracted on the data: jump magnitudes aren't
    multiples of 360deg, and the implied rate is far below what could
    even mi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
    [ServoDAQ_Companion.ino, servo_daq.py]
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2026-08-19 ServoDAQ: remove obsolete one-off investigation scripts
    probe_low_jump.py, hand_stall_test.py, watch_full_swing_jump.py, and
    full_test_record.py were ad hoc diagnostic tools written for the
    2026-08-16/17 stall-recovery-backoff investigation -- not part of the
    standard study_range.py procedure, and their findings are already
    fully captured in prose in CLAUDE.md and ServoDAQ/README.md. Also
    cleaned up this session's own scratchpad debugging scripts (the
    NOT_SETTLED/spin-past-the-edge investigation), never part of the repo.
    Still recoverable from git history if a similar question ever comes
    up again -- this isn't a claim the investigation itself is somehow
    less valid, just that the throwaway t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
2026-08-19 MATLAB: name motors by their actual model, sync axes within a type
    motorTypeNames.m: new lookup, type number -> physical servo model name
    (mirrors ServoDAQ/MOTOR_TYPES.md). setup.m resolves it onto each
    MotorTypeData.TypeName. Every plot now identifies a unit by its actual
    name and unit number ("Miuzei 25kg Servo Unit 2"), never bare
    "type1 unit2" -- "Type <N>" only survives as a last-resort fallback
    for a type with no lookup entry, via a shared typeLabel()/unitLabel()
    pair duplicated in each of the four plotting scripts.
    Also: within one type's figure, every unit's axes now share identical
    scale, via a shared syncAxes() helper (also duplicated per script,
    matching this project's standalone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
2026-08-21 Add ServoAutoCalibrator: on-device FSM calibration with spin-recovery
    New standalone tool -- same coarse+fine stall-scan concept as
    ServoDAQ, rebuilt as a self-contained FSM (one switch/case in
    loop(), fixed 50Hz tick) that needs no host script once calibration
    starts.
    Root-cause fix: servo.attach() without explicit pulse bounds silently
    clamped every writeMicroseconds() call below ~540us to the Servo
    library's own default floor -- looked exactly like a physical stall,
    wasn't. Fixed with explicit ABS_FLOOR_US/ABS_CEIL_US bounds, same
    approach as ServoDAQ_Companion.
    Active spin-recovery (STATE_CAL_RECOVER_WAIT): a settle-timeout can
    only detect a servo-triggered spin after the fact, not pre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
2026-08-21 ServoDAQ: fix naive-sweep first-step stiction bug, study complete at 9 units
    naive_stall_sweep()/scan_until_weak() fed their first tracked step
    into stall/reference-rate judgment on equal footing with every later
    step -- but a servo's first move from a standing start reliably reads
    weaker than its cruise rate (stiction), corrupting the whole scan's
    threshold. Fixed: both now record the first point but exclude it from
    judgment entirely. Verified via three real reruns (broken -> still
    broken with a wrong-theory fix -> correct with the real fix).
    Also: a third Miuzei 25kg Servo unit was added to the study (now 3
    units per family, 9 total, all with completed accuracy runs --
    55,029 trials). CLA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
    [plot_naive_vs_smart.py, servo_daq.py, study_range.py]
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2026-08-22 article.md: add gearing and backlash characterization charts
    New section, 'The servos aren't built the same, mechanically' --
    pulse-width-per-degree and mean/max backlash by family, both drawn
    from data the study already collected (every unit's fine sweep) but
    hadn't made it into the article yet.
2026-08-22 article.md: fix chart issues from review
    - Accuracy-vs-model-complexity chart: the linear2 reference line now
    joins directly to the table10 point (was a full-width flat
    reference, disconnected from the actual data series).
    - Drift diagram: widened the viewBox so the radius-callout labels no
    longer run outside it, and clarified explicitly (inline labels,
    legend, caption) that 8.4mm/2.7mm are radii -- the distance from
    the commanded point to where the end effector actually lands -- not
    diameters.
2026-08-22 article.md: rework drift diagram to fill the site's new wider chart breakout
    The website's global.css now lets chart-figure break out to up to 64rem
    wide on screens above 56rem, with the intent that a wider card also
    means bigger axis labels/data-point text -- not just more empty
    whitespace. The drift diagram's original 780x300 layout concentrated
    everything in the upper-left, leaving a large empty lower-right
    quadrant once stretched that wide. Rescaled and repositioned the whole
    composition (larger joints, longer links, bigger drift circles, larger
    label text) to actually use the wider frame, verified visually at a
    1600px viewport against the live site's new styling.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
2026-08-22 The FSM firmware becomes THE companion; rewrite ServoCalibrator.html to match
    Per explicit direction, the FSM redesign (formerly developed under a
    separate ServoAutoCalibrator/ folder) is now what ServoCalibrator.html
    talks to -- moved into ServoCalibrator_Companion/ServoCalibrator_Companion.ino
    (git mv, replacing the older, structurally different companion firmware
    that used to live at this path -- still recoverable from git history).
    ServoAutoCalibrator/ is gone.
    ServoCalibrator.html was rewritten against the new protocol rather than
    built fresh, reusing its proven layout/CSS/chart code and busy-lock
    design. Real, deliberate protocol differences the rewrite designs
    around: CAL acks immedi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
    [ServoCalibrator_Companion.ino]
2026-08-22 ServoCalibrator_Companion: reduce position-filter smoothing, fix stray boot banner
    CAL_POSITION_FILTER_SAMPLES 10 -> 3 (200ms -> 60ms at this 50Hz tick)
    per direct feedback that the live TELEM trace read too smooth --
    filteredPosition isn't reporting-only, it also feeds the calibration
    table itself, a GO move's planned start, and the scan's own edge
    detection, so this affects more than just the chart. Verified on real
    hardware: idle position now visibly jitters between adjacent AS5600
    counts instead of reading one flat number.
    Also fixed the boot banner still printing the pre-rename
    "ServoAutoCalibrator booting..." string -- the .ino's header comment
    was updated in the previous commit, this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
    [ServoCalibrator_Companion.ino]
2026-08-22 ServoCalibrator_Companion: TELEM reports raw position, not filtered
    Per explicit direction: printTelemetry() now sources actual position
    from a new rawAngleCentideg() (totalCounts directly, no averaging)
    instead of currentAngleCentideg() (filteredPosition-based). Velocity
    was already raw (encoderDerivative). filteredPosition itself -- still
    feeding the calibration table (recordTableEntry), a GO move's planned
    start (currentAngleDeg), and the scan's own edge-detection
    (updateStepDelta) -- is untouched by this and got its own window
    (CAL_POSITION_FILTER_SAMPLES) bumped back up 3->5 (60ms->100ms), since
    decoupling TELEM from it means a slightly longer window no longer costs
    the live trace any r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
    [ServoCalibrator_Companion.ino]
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2026-08-22 ServoCalibrator_Companion: fine pass stops on edge-found, not fixed margin
    The fine pass was unconditionally walking its entire CAL_FINE_MARGIN_US
    margin (20 fixed 5us steps) regardless of what it found along the way
    -- a plain stall was noted and swept straight through, only reversed/
    anomaly ended it early. That was never the actual algorithm: center ->
    coarse down, back off 100us once found -> fine down UNTIL FOUND (same
    detection/sensitivity as coarse) -> center -> coarse up, back off ->
    fine up until found -> record table down from the up edge, reverse,
    average.
    STATE_CAL_DOWN_WAIT/STATE_CAL_UP_WAIT's fine branches now stop on the
    exact same condition as their own coarse branches (spin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
    [ServoCalibrator_Companion.ino]
2026-08-22 ServoCalibrator_Companion: port coarse+fine edge detection exactly from servo_daq.py
    Per direct instruction ("make calibration mimic exactly what the python
    study did for calibration minus the naive run, just coarse and fine"),
    replaced the firmware's ad hoc absolute-threshold stall detection with
    servo_daq.py's actual scan_until_weak()/find_edge() algorithm, kept
    inside the existing FSM structure:
    - Each of the 4 scans (coarse/fine x down/up) self-calibrates its own
    baseline step rate from its first 5 real steps, then judges every
    later step as weak/reversed/oversized purely relative to that scan's
    own rate -- no fixed absolute thresholds.
    - First-step exclusion from rate/edge judgme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
    [ServoCalibrator_Companion.ino]
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2026-08-22 Move website content into a website/ folder; fill out tool.md frontmatter
    Establishes a site-wide convention (applied the same way across every
    project repo the website pulls from): everything a repo feeds to
    vishwamaggarwal.com lives under one website/ folder instead of loose at
    repo root.
    - article.md, data.md -> website/article.md, website/data.md
    - test-jig.jpg -> website/images/test-jig.jpg
    - Hookup.png -> website/images/hookup.png (lowercased to match the path
    tool-page.md already referenced)
    - ServoCalibrator.html -> website/app.html -- renamed, not just moved,
    so every tool's app is predictably website/app.html regardless of what
    the tool itself is called
    - tool-page.md -> web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
    [ServoCalibrator_Companion.ino]
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2026-08-22 Add website/sources/ convention for editable diagram sources
    Standardizes where an editable source behind an image in website/images/
    lives (Fritzing .fzz, KiCad/Eagle, Illustrator, whatever) -- one folder,
    named to match the exported image's basename exactly
    (website/images/hookup.png <-> website/sources/hookup.fzz), never
    fetched/served by the website itself, pure repo-side hygiene for
    whoever edits the diagram later.
    Moves the loose website/Hookup.fzz (left at website/ root, mismatched
    casing from website/images/hookup.png) into website/sources/hookup.fzz
    as the first real instance of the convention.
    Also updates website/STYLE_GUIDE.md, copied from the website repo's
    canonical version.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
    [hookup.fzz]
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2026-08-25 Fix ABS_CEIL_US silently overflowing the Servo library's int8_t encoding
    ABS_CEIL_US was 3100 in both ServoCalibrator_Companion.ino and
    ServoDAQ_Companion.ino (plus servo_daq.py's mirrored constant). The AVR
    Servo library encodes attach()'s bounds internally as
    (MAX_PULSE_WIDTH - max)/4 in a signed int8_t (MAX_PULSE_WIDTH 2400) --
    for 3100 that's (2400-3100)/4 = -175, which doesn't fit in int8_t and
    silently wraps to 81, giving an actual enforced ceiling of
    2400 - 81*4 = 2076us. Every commanded pulse above ~2076us was silently
    rewritten to 2076us, indistinguishable from a genuine stall -- which is
    exactly what both firmwares' rate-based edge detection dutifully (and
    correctly, given the inpu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
    [ServoCalibrator_Companion.ino, ServoDAQ_Companion.ino, servo_daq.py]
2026-08-26 Normalize calTable on-device to [0, maxAngleDeg] for UMI compatibility
    ServoCalibrator_Companion.ino built calTable from raw AS5600 readings
    relative to wherever the board happened to boot -- index 0 didn't read
    0 degrees, and only website/app.html reframed it client-side. UMI's
    ServoCalibrationTable.h::validateCalTable() expects a table already in
    that [0, maxAngleDeg] frame (table[0].angleCentideg <= 0, strictly
    ascending, coverage up to maxAngleRad), so this firmware's own
    GETTABLE/TABLE output didn't actually satisfy it on its own.
    calOffsetCentideg/calSign are now computed once, right when a CAL run's
    table finishes building, and applied to calTable/linearTable in place.
    Since calTable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
    [ServoCalibrator_Companion.ino]
2026-08-30 Adopt the current Universal-* stack: UDI dependency, UEI encoder path
    The Universal-*-Interface family grew from two libraries to six. Two of
    them affect this repo.
    Universal-Trajectory-Interface now declares `depends=Universal Device
    Interface`, and its TrajectoryGroup/CartesianMove were retrofitted onto
    IDevice. This firmware uses neither class, but the Arduino build compiles
    every .cpp in a library's src/, so their `#include <IDevice.h>` is
    unconditional. Verified by building in an isolated sketchbook holding
    exactly what this repo's own docs prescribed (AS5600 + UTI): `fatal
    error: IDevice.h: No such file or directory`. TrapezoidalProfile itself
    was deliberately left off that retrofit a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
    [ServoCalibrator_Companion.ino, ServoDAQ_Companion.ino]
